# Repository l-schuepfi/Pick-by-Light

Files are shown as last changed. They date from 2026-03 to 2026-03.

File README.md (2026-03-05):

# Entwicklung eines Pick-by-Light-Systems zur Effizienzsteigerung in der Kommissionierung

## Projektbeschreibung

Im Rahmen dieser Projektarbeit wurde ein bestehendes Pick-by-Light-System in der Lernfabrik (KA.409) der Technischen Hochschule Nürnberg erneuert und erweitert. Ziel war die Effizienzsteigerung im Kommissionierprozess durch eine automatisierte Auftragsselektion, Eingriffsüberwachung und Stückzahlüberprüfung. Das System wurde auf Basis eines Raspberry Pi 4B und eines Arduino Uno realisiert und ist vollständig in Python (Raspberry Pi) bzw. C++ (Arduino) implementiert.

| VORHER | NACHHER |
| :---: | :---: |
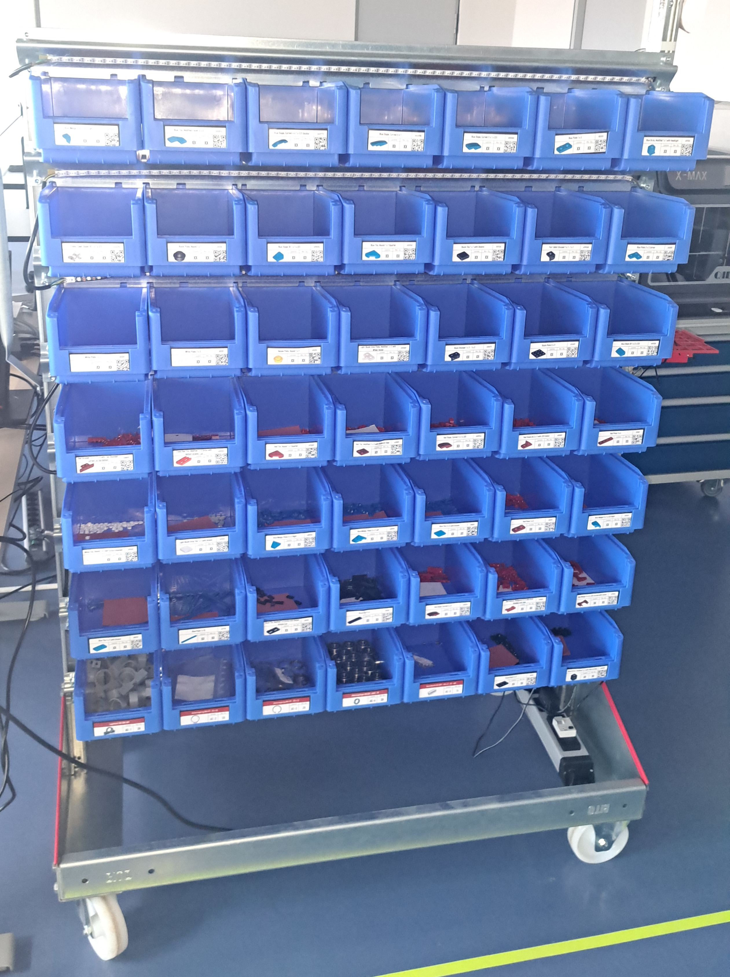
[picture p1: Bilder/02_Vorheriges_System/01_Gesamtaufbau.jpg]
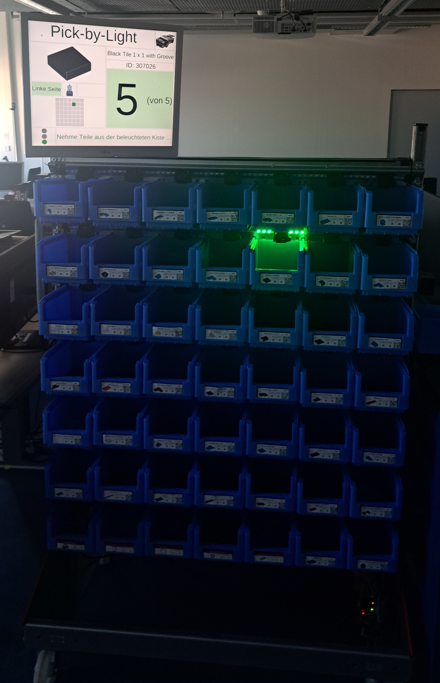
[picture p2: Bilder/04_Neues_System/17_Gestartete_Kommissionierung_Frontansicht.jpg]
|  |  |

**Kernkomponenten:**

- **RFID-basierte Auftragsselektion** – Automatische Erkennung der eingeführten Kiste
- **Infrarot-Eingriffsüberwachung** – Erkennung von Entnahmen aus den Kisten
- **Wägezelle zur Stückzahlüberprüfung** – Gewichtsbasierte Kontrolle der entnommenen Teile
- **LED-Streifen & Monitor (HMI)** – Visuelle Führung des Kommissionierers

## Konzeptionierung inkl. Bewertung

Die Konzeptionierung orientierte sich am mechatronischen V-Modell. In einem ersten Schritt wurden auf Basis einer Swimlane-Funktionsstruktur die Teilfunktionen des Systems identifiziert.

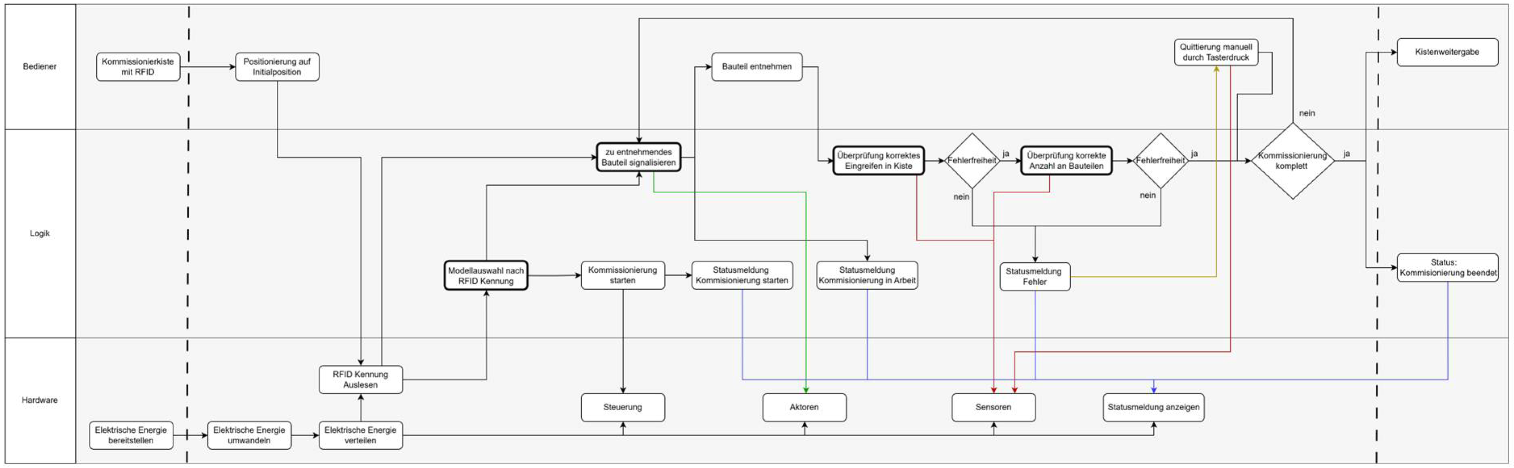
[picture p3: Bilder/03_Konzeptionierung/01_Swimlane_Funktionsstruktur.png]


### Anforderungsliste

Die Anforderungsliste definiert die funktionalen und nicht-funktionalen Anforderungen an das System, z. B. Fehlerraten der Sensorik (< 0,5 %), Kostenziel (300 €), maximales Gesamtgewicht (< 200 kg) und Einarbeitungszeit.

### Morphologischer Kasten

Für jede Teilfunktion wurden im morphologischen Kasten mehrere technische Lösungsvarianten gegenübergestellt – darunter verschiedene Identifikationsverfahren (RFID, Barcode, QR-Code), Sensorprinzipien zur Eingriffsüberwachung (Infrarot, Ultraschall, Laser) und Möglichkeiten zur Stückzahlprüfung (Waage, Kamera, manuell).

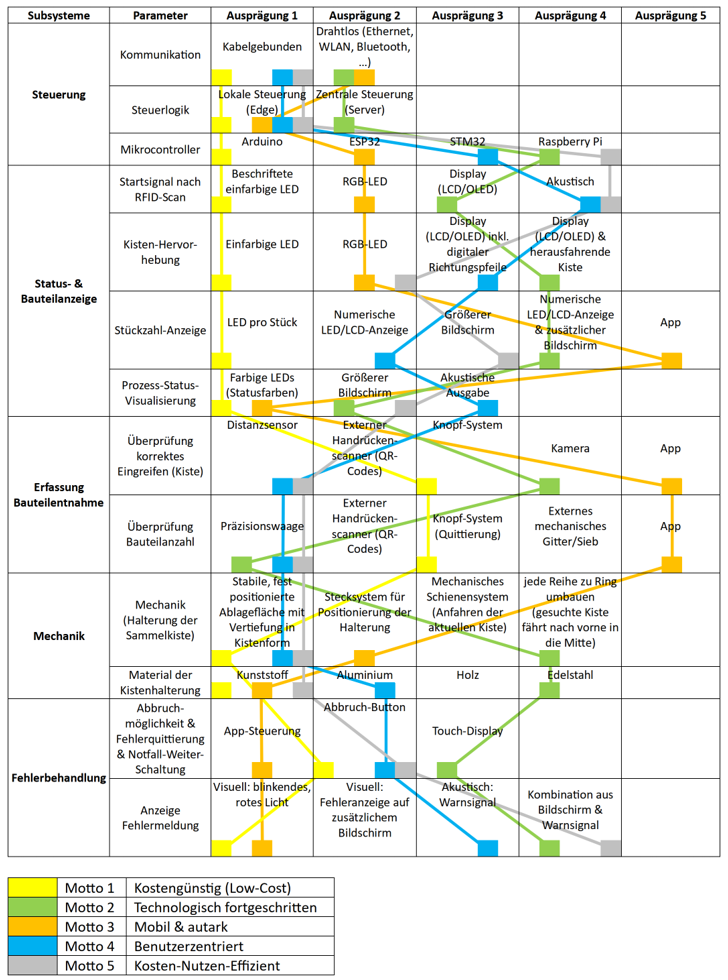
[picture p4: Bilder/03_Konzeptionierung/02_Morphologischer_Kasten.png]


### Paarweiser Vergleich

Über einen konsolidierten paarweisen Vergleich wurde die Gewichtung der einzelnen Anforderungen bestimmt. Drei Personen haben unabhängig voneinander bewertet, um eine möglichst objektive Priorisierung zu erreichen.

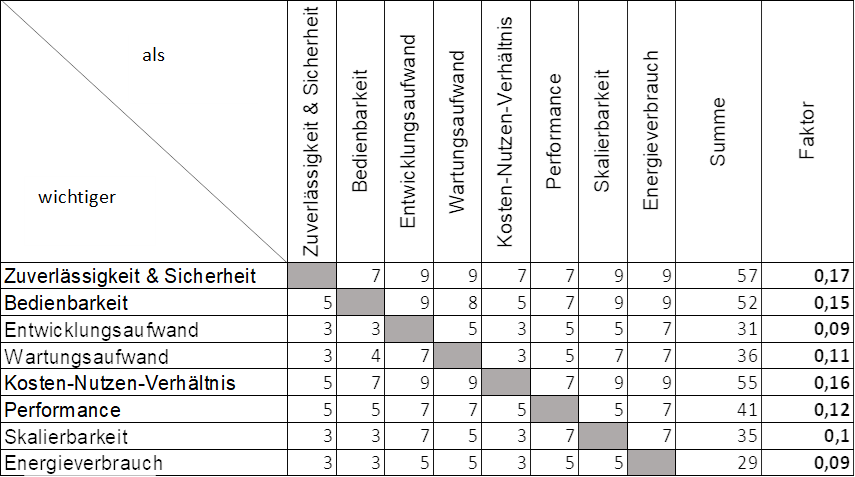
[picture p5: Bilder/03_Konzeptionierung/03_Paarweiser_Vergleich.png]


### Nutzwertanalyse

Auf Basis des paarweisen Vergleichs wurde eine Nutzwertanalyse durchgeführt, um die beste Gesamtlösung aus den Varianten des morphologischen Kastens zu ermitteln. Das gewählte Konzept kombiniert RFID für die Auftragsselektion, Infrarot-Module für die Eingriffsüberwachung und eine Wägezelle für die Stückzahlüberprüfung.

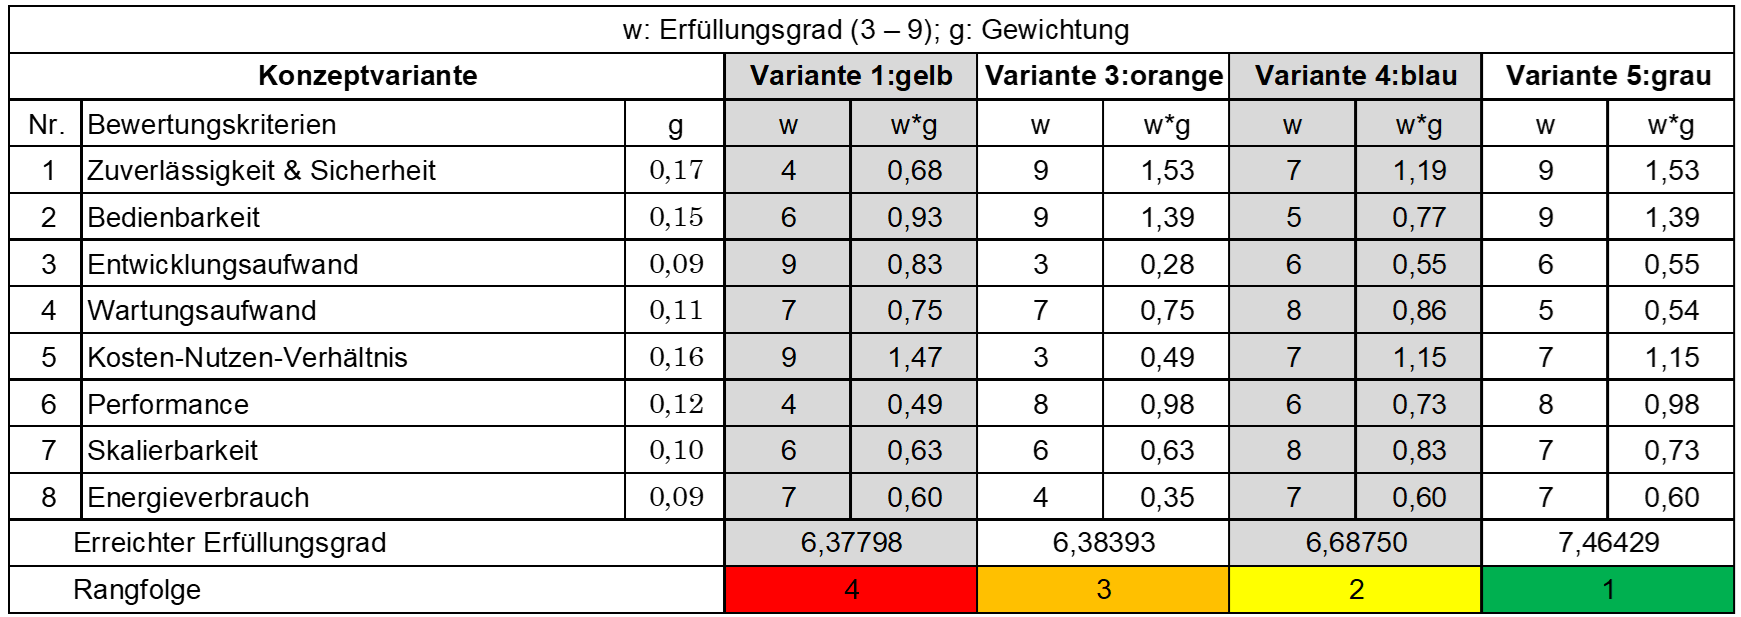
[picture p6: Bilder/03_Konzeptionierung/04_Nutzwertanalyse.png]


## Umsetzung

### Kommissionierungsauswahl – RFID

Jede Kiste besitzt einen RFID-Transponder, der beim Einschieben in die Halterung vom RFID-Modul (RC522) über SPI ausgelesen wird. Anhand der UID wird der zugehörige Kommissionierauftrag aus einer Excel-Datenbank geladen. Das RFID-Lesegerät ist in einem 3D-gedruckten Gehäuse in die Kistenhalterung integriert, um einen zuverlässigen Leseabstand zum Transponder sicherzustellen.

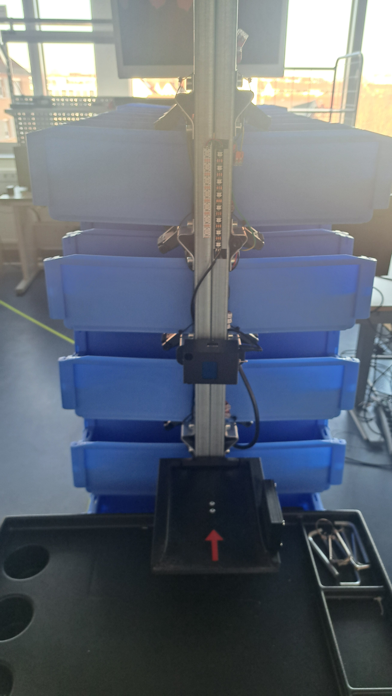
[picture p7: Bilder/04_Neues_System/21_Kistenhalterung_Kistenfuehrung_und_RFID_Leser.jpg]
Kistenfuehrung und RFID-Leser


### Eingriffsüberprüfung – Infrarot

Vor jeder Kiste sitzt ein Infrarot-Modul bestehend aus einer IR-Diode (Sender) und einem IR-Empfänger (TSSP4P38, 38 kHz Trägerfrequenz). Die Dioden werden über eine MOSFET-Schaltung mit einem gepulsten 5 V-Signal angesteuert. Die IR-Empfänger werden über MCP23017-I/O-Expander per I2C am Raspberry Pi ausgelesen. Beim Eingriff in eine Kiste wird der IR-Strahl frühzeitig reflektiert und der Eingriff aufgrund erhöhter Signalstärke erkannt. Die Module sind in 3D-gedruckten Gehäusen mit einstellbarem Sendewinkel verbaut. Beim Systemstart erfolgt eine automatische Kalibrierung jedes Moduls.

### Stückzahlüberprüfung – Waage

Eine 1 kg-Wägezelle mit HX711-ADC wird über den Arduino Uno ausgelesen, da der Raspberry Pi aufgrund seines Betriebssystem-Timings keine stabilen Messwerte liefern konnte. Die Kommunikation zwischen Arduino und Raspberry Pi erfolgt über die serielle USB-Schnittstelle. Das System erkennt Gewichtssprünge und berechnet über das bekannte Einzelgewicht der Bauteile die Anzahl der entnommenen Teile. Die Kalibrierung der Waage kann über einen langen Taster-Druck gestartet werden und nutzt ein 200 g-Referenzgewicht. Der Kalibrierungswert wird im EEPROM des Arduino gespeichert.

Die Wägezelle ist als zentrales Verbindungselement zwischen Trägergestell und Kistenaufnahme montiert, wobei die einseitige Befestigung die elastische Verformung für das Messprinzip gewährleistet.

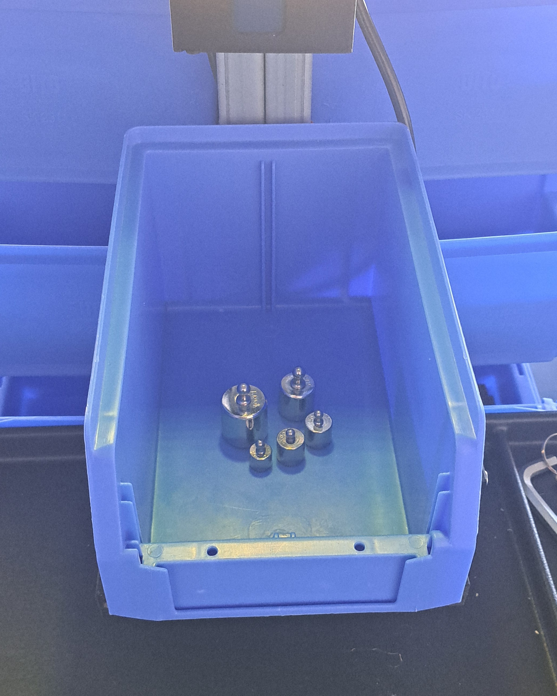
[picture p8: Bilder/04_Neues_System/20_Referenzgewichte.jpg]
Referenzgewichte an Waage


### Signalisierung zu entnehmende Kiste und Anzahl der zu entnehmenden Teile

#### LED-Strip

Zwei WS2812B-LED-Streifen signalisieren dem Kommissionierer die aktuell zu entnehmende Kiste (grün leuchtend). Die Ansteuerung erfolgt über den Raspberry Pi, wobei ein SN74AHCT125N Level-Shifter die 3,3 V-Signale auf die benötigten 5 V anhebt.

#### HMI

Die grafische Oberfläche läuft als Tkinter-Anwendung auf dem Raspberry Pi und zeigt auf einem Monitor den aktuellen Kommissionierstatus, die zu entnehmende Stückzahl und Fehlermeldungen an. Da die GUI-Mainloop und die Sensorauswertung parallel laufen müssen, wurde die Architektur auf drei Prozesse (Multiprocessing) aufgeteilt:

1. **GUI-Prozess** – Aktualisierung der Anzeige
2. **Messschleife** – Auslesung der IR-Module über I2C
3. **Wägezellen-Prozess** – Auslesen der Gewichtswerte über den Arduino

Die Kommunikation zwischen den Prozessen erfolgt über Queues.

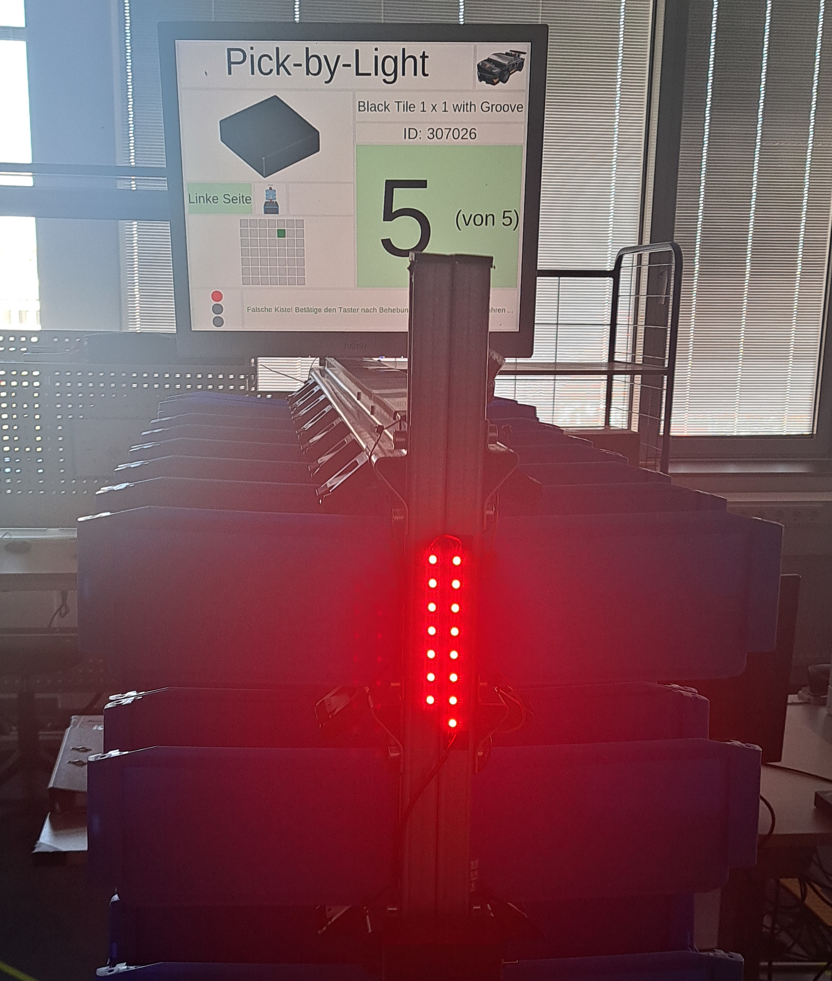
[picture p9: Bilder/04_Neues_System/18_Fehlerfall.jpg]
Fehlerfall


### Systemintegration und Realisierung

- **Controller:** Raspberry Pi 4B (Hauptcontroller) + Arduino Uno (Waage + IR-Pulssteuerung)
- **Hutschiene:** Alle Elektronikbauteile sind modular über DIN-Schiene montiert
- **Schaltnetzteil:** 50 W / 10 A Netzteil für die IR-Dioden, in einem Schutzgehäuse verbaut
- **MOSFET-Schaltung:** IRLZ44N (N-Kanal) + IXTP96P085T (P-Kanal) zur Erzeugung des 38 kHz-Pulssignals auf einer Lochrasterplatine
- **Taster:** Interrupt-basierte Auswertung am GPIO26 mit Unterscheidung zwischen kurzem Druck (Weiterschalten), langem Druck (Kalibrierung / Zurückschalten) und Doppeldruck (Abbruch)
- **Kistenhalterung:** 3D-gedruckte Führung mit Nut-Feder-Prinzip für reproduzierbare Positionierung der Kiste und integriertem Kabelkanal
- **Autostart:** Das Programm startet automatisch nach dem Hochfahren des Raspberry Pi

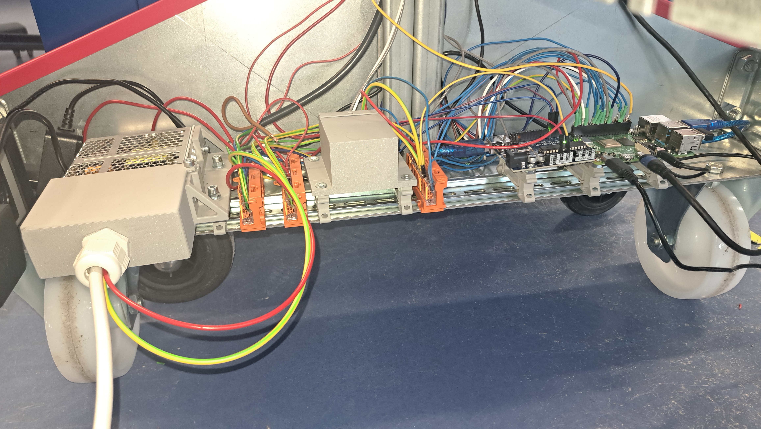
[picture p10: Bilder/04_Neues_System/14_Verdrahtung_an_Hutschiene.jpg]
Verdrahtung an Hutschiene


## Validierung und Tests

Die Validierung erfolgte anhand der definierten Anforderungsliste. Die meisten funktionalen Anforderungen konnten bestätigt werden, einige Punkte waren zum Testzeitpunkt nicht prüfbar (z. B. Gesamtgewicht, Energieverbrauch, Einarbeitungszeit).

| Teilsystem | Fehlerrate (gemessen) | Fehlerrate (Soll) | Ergebnis |
|---|---|---|---|
| **RFID-Erkennung** | 0 % (30 Versuche) | < 0,5 % | ✅ Erfüllt |
| **Eingriffsüberwachung** | 12,5 % (14 Kisten × 20 Zyklen) | < 0,5 % | ❌ Nicht erfüllt |
| **Stückzahlüberprüfung** | 22,5 % (4 Teile × 3 Mengen × 10 Zyklen) | < 0,5 % | ❌ Nicht erfüllt |

Die Eingriffsüberwachung ist stark abhängig von der Geschwindigkeit des Bedieners – langsame Eingriffe werden zuverlässig erkannt, schnelle nicht immer. Das Kostenziel von 300 € wurde mit ca. 500 € überschritten, hauptsächlich durch Leitungen und Verbindungselemente.

## Verbesserungsmöglichkeiten

- **Infrarot-Sensorik:** Kürzere Sende-/Pausenzeiten (< 120 ms / < 380 ms) und angepasster Duty Cycle könnten schnelle Eingriffe besser erkennen. Alternative Kalibrierungsverfahren (Median statt Mittelwert) wären ebenfalls vielversprechend.
- **LED-Streifen:** Austausch des fragilen Systems empfohlen; einheitliche Farbcodierung und Stützkondensator am Level-Shifter nachrüsten.
- **Waage:** Bedingung einbauen, dass vor Waagenauswertung ein korrekter IR-Eingriff erkannt sein muss. Negative Sprünge als Fehlermeldung auswerten.
- **RFID:** Beschreibung der Tags mit Daten statt UID-Zuordnung im Code, um neue Kisten ohne Programmänderung einbinden zu können.
- **Verkabelung:** Farbcodierung vereinheitlichen (aktuell teils grün-gelb als GND statt normgerecht als PE). Alternative Kommunikationswege (z. B. Bluetooth) zur Reduzierung der Leitungsintensität prüfen.
- **Software:** Tonausgabe bei Fehlern über USB-Soundkarte, schönere GUI, LED-Zuordnung austauschfreundlicher gestalten.

## Fazit und Ausblick

Das Pick-by-Light-System wurde erfolgreich als funktionsfähiger Prototyp umgesetzt. Die Auftragsselektion per RFID funktioniert zuverlässig (0 % Fehlerrate). Die Eingriffsüberwachung und Stückzahlüberprüfung zeigen grundsätzliche Funktionsfähigkeit, erreichen die geforderten Fehlerraten aber noch nicht. Insbesondere die Abhängigkeit der IR-Erkennung von der Eingriffgeschwindigkeit und die Drift der Wägezellenwerte stellen Herausforderungen dar, die durch die vorgeschlagenen Optimierungen adressiert werden können.

Das System bietet eine solide Grundlage für zukünftige Weiterentwicklungen im Rahmen der Lernfabrik.

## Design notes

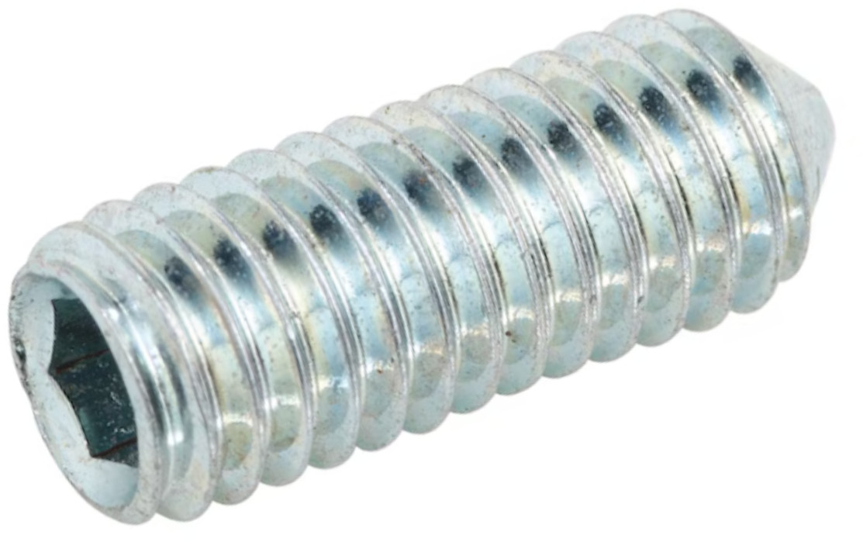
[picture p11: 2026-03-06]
Code/Raspberry_Pi/img/Left_Side/L007005.jpg

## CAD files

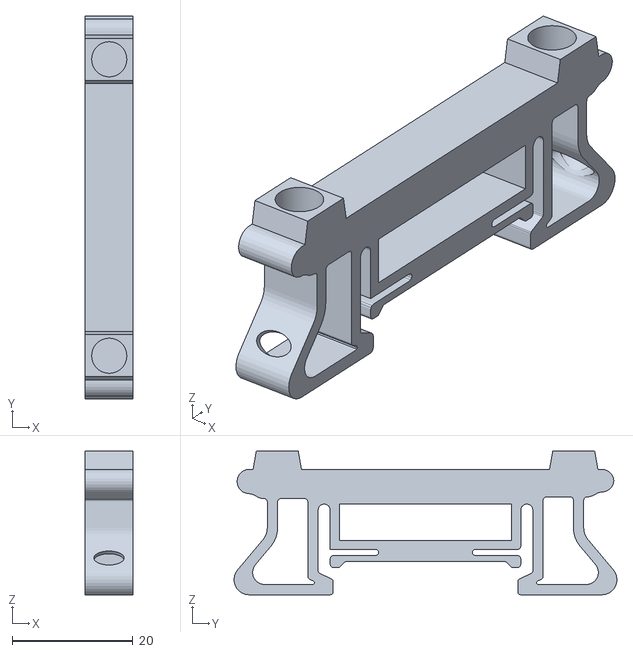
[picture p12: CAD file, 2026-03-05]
CAD/Hutschiene/clips_2.stl
8.00 x 63.3 x 23.7

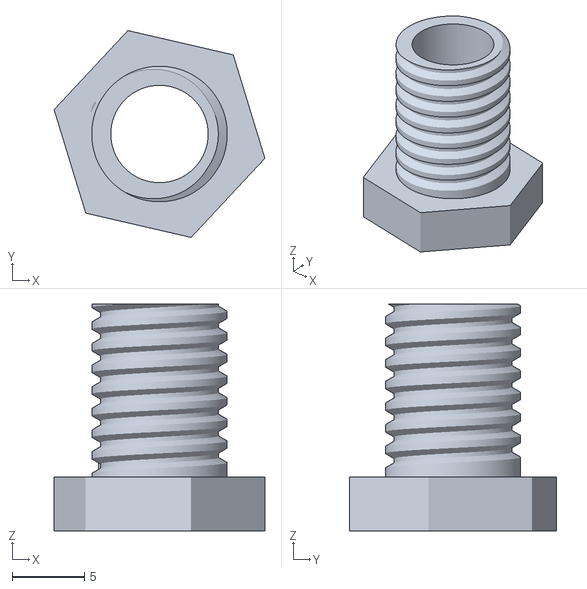
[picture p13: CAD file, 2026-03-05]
CAD/IRModul/Schraube_M10x1.stl
14.6 x 14.4 x 15.8

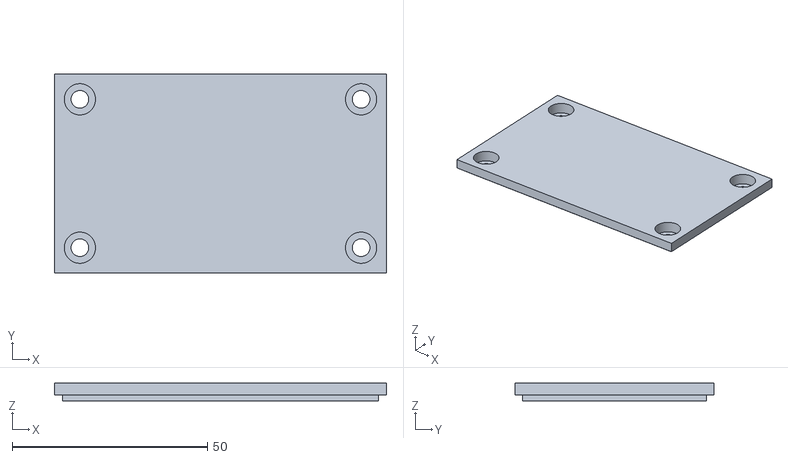
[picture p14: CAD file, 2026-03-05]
CAD/Kistenhalterung/RFID_Deckel.stl
85.0 x 51.0 x 4.50

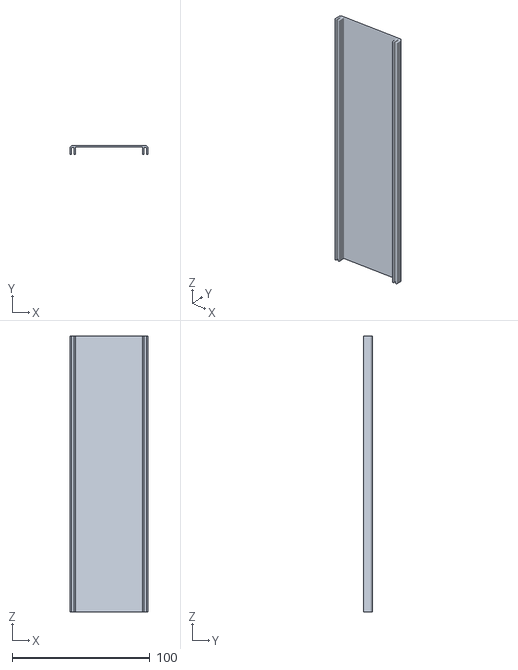
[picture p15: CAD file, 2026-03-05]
CAD/Sonstiges/Kabelkanaldeckel_2.stl
56.6 x 6.50 x 200.0

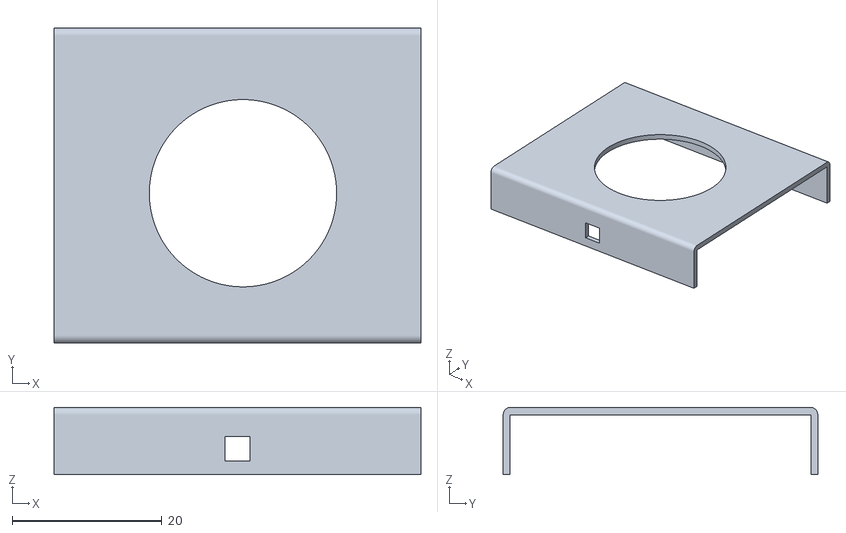
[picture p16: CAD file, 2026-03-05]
CAD/Hutschiene/Deckel_Platinegehäuse.stl
49.0 x 42.0 x 9.00

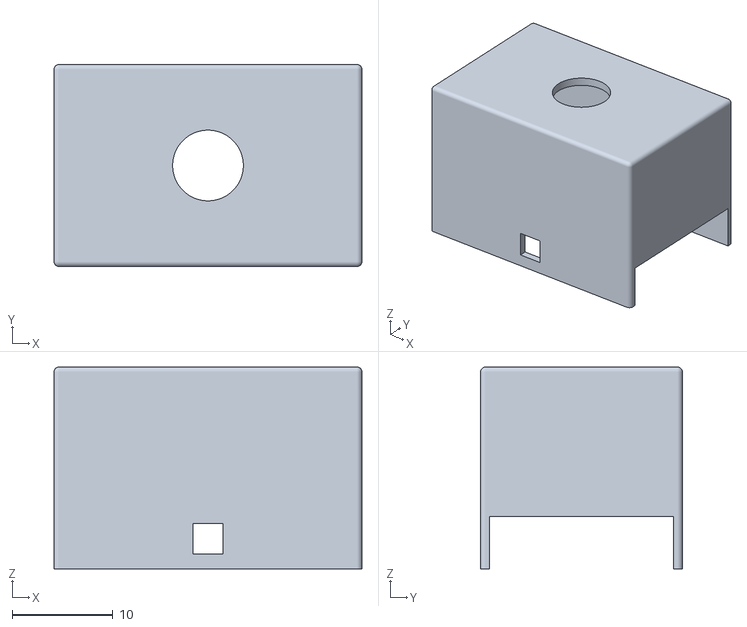
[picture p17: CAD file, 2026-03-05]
CAD/IRModul/Deckel_lang.stl
30.5 x 20.0 x 20.0

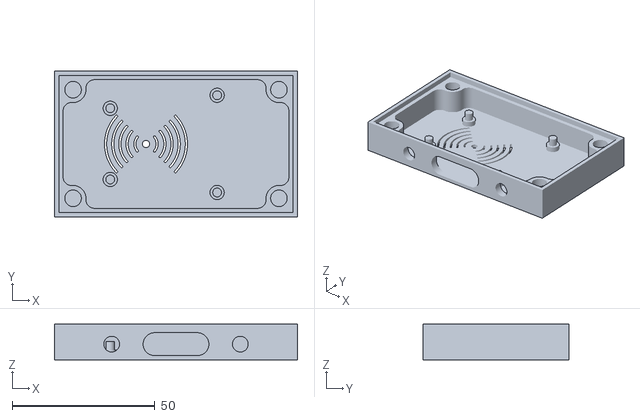
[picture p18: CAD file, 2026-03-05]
CAD/Kistenhalterung/RFID_Gehäuse.stl
85.0 x 51.0 x 12.5

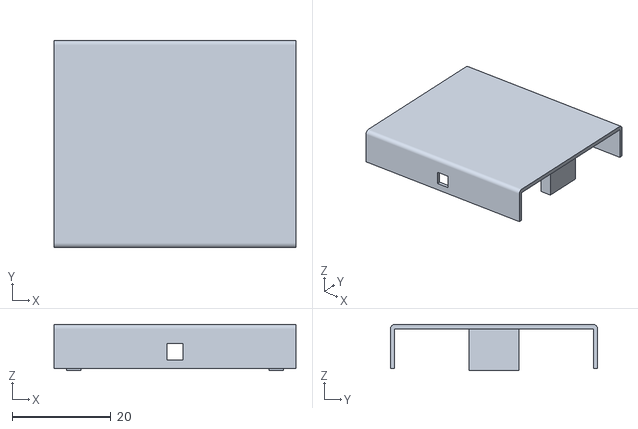
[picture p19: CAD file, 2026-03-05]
CAD/Sonstiges/MCP_Deckel.stl
49.0 x 42.0 x 9.40

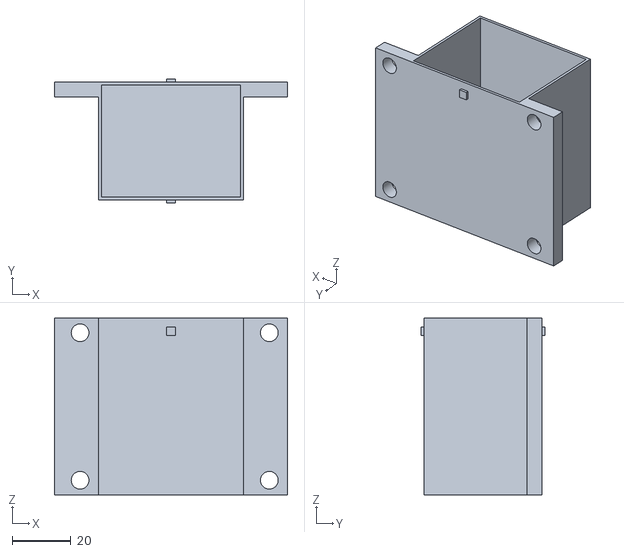
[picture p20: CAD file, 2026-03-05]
CAD/Hutschiene/Platine_Halterung.stl
79.0 x 42.0 x 60.0

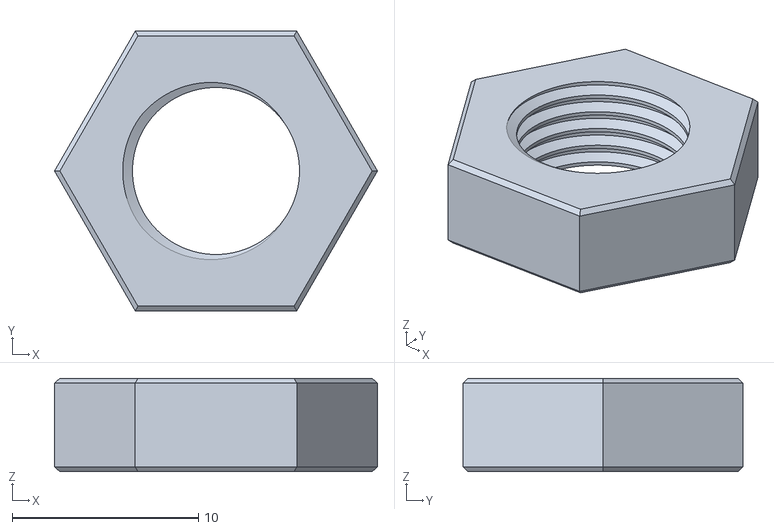
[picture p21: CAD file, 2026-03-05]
CAD/IRModul/Mutter M10x1_flach.stl
17.3 x 15.0 x 5.00

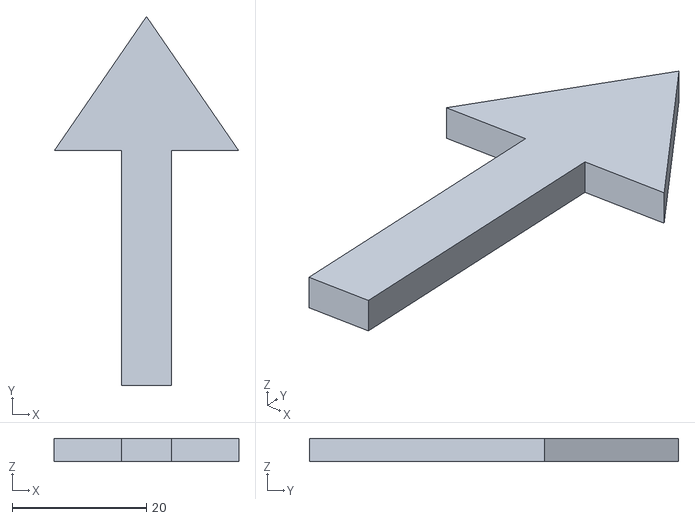
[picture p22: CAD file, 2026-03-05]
CAD/Kistenhalterung/Pfeil.stl
27.5 x 55.0 x 3.50

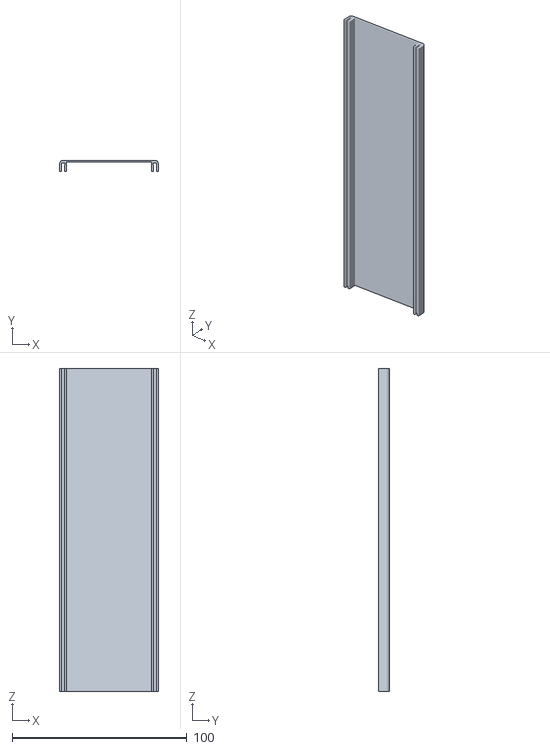
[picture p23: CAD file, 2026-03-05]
CAD/Sonstiges/Kabelkanaldeckel_18.5cm.stl
56.6 x 6.50 x 185.0

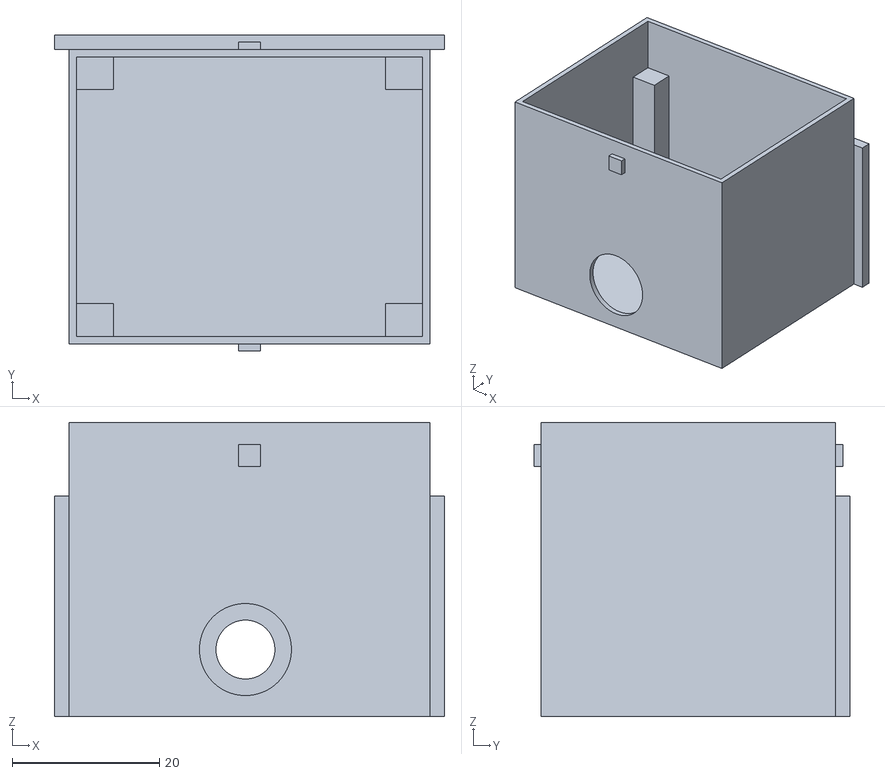
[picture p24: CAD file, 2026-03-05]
CAD/Sonstiges/MCP_Gehäuse.stl
53.0 x 43.0 x 40.0

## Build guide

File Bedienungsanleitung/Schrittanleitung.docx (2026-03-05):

Bedienungsanleitung Pick-by-Light-System der Lernfabrik

In diesem Dokument soll beschreiben werden, wie das Pick-by-Light-System der Lernfabrik (KA.409) zu bedienen ist.

Grundsätzlich kann damit die Kommissionierung der folgenden drei Legoautos begleitet werden:

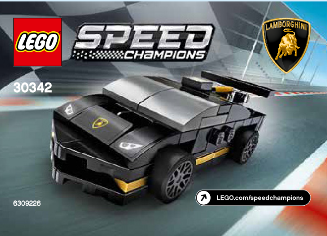
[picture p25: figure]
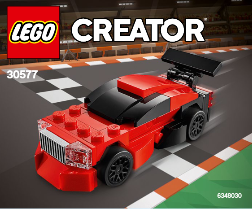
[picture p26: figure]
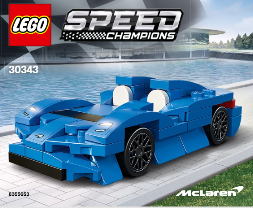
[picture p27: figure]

Bedienreihenfolge:

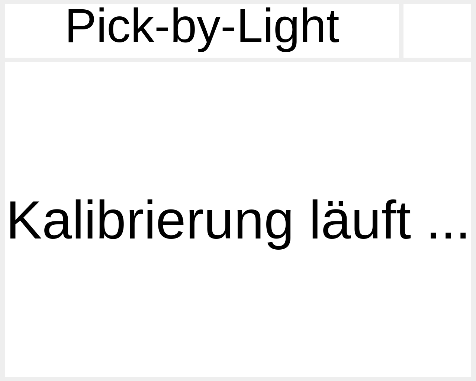
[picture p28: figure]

Schritt 1: Versorgung aktivieren (Steckdose einstecken, Schalter unten umlegen)

Hier ist abzuwarten, bis das System hochgefahren ist.

Schritt 2: Kalibrierung

Hier ist einfach abzuwarten (grob 5-10 Sekunden)

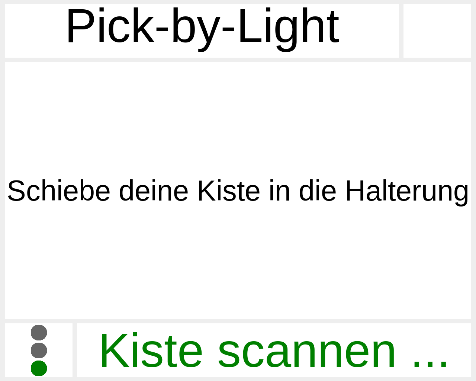
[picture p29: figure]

Schritt 3: Auftragsselektion

Im Durchlaufregal des Labors sind blaue Kisten, die seitlich mit einem RFID-Tag beklebt sind. Diese Kisten sind so einsortiert und der jeweilige Kanalplatz auch beschriftet, dass jeder Kanalplatz für einen Typen Legoauto steht. Allerdings sind zum Zeitpunkt der Abgabe nur drei Kisten funktionstüchtig (andere werden vom RFID-Scanner nicht erkannt)

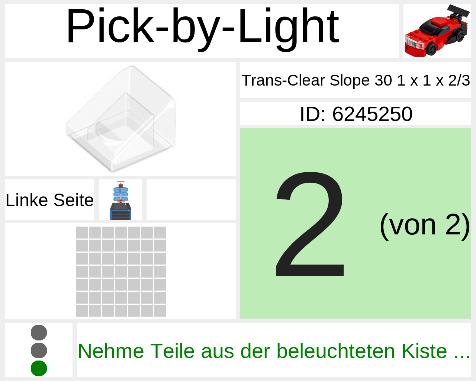
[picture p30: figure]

Schritt 4: in Startposition bringen

Nachdem eine Kiste mit gewolltem Legoautotypen entnommen wurde, muss diese nun in die Startposition am Pick-by-Light-System eingesetzt werden. Hierbei wird automatisch der RFID-Tag der Kiste erkannt und ausgelesen und die Kommissionierung startet. Der Bildschirmscreen ändert sich.

Bemerkung: Die Kiste in Startposition soll erst nach Ende der Kommissionierung wieder aus dieser Position entfernt werden.

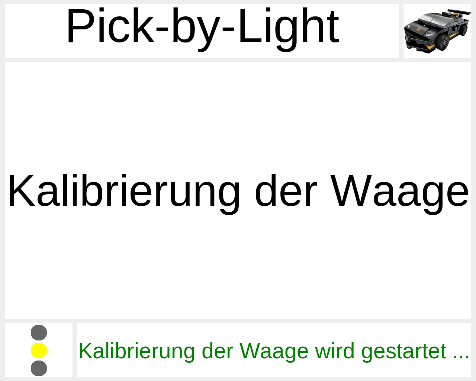
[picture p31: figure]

Optionaler Schritt 5: Kalibrierung

5.1 Durch einen langen Druck auf den Taster wird der Kalibierungsmodus der Wägezelle aktiviert (nur möglich solange noch kein Kisteneingriff erkannt wurde)

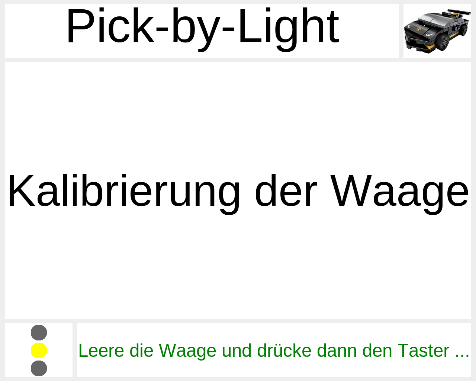
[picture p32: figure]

5.2 Hierfür muss die Kiste leer sein → ggf. leeren

5.3 Bestätigung per Taster

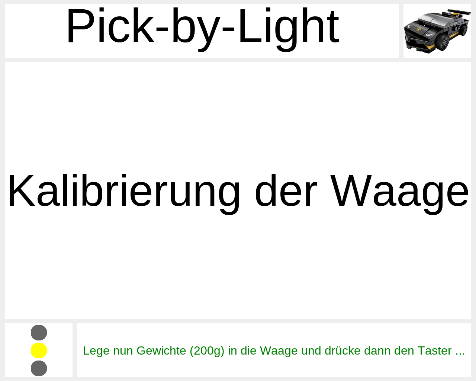
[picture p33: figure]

5.4 200gr Referenzgewicht in die Kiste legen

5.5. Bestätigung per Taster

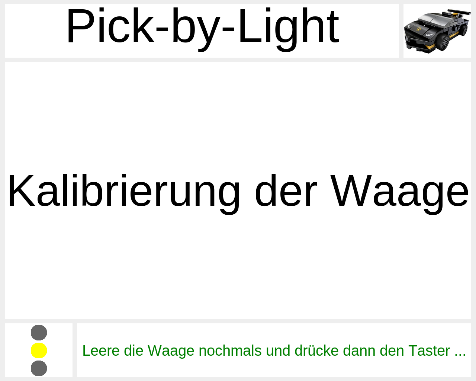
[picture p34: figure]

5.6 Referenzgewicht entnehmen

5.7 Bestätigung per Taster

Anschließend startet die Kommissionierung und der Screen ändert sich.
Der Kommissionierer wird auch vom Bildschirm durch entsprechende Anweisungen unterstützt.

Schritt 5: Kommissionierung

Nun werden am Bildschirm die Position sowie Anzahl des zu entnehmenden Teiles angezeigt. Zusätzlich leuchten die LEDs des LED-Strips oberhalb der zu entnehmenden Kiste.

Schritt 5.1: Entnahme

Entnehmen Sie die angezeigte Anzahl aus der visuell hervorgehobenen Kiste.

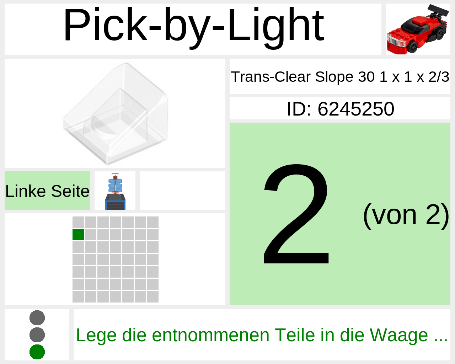
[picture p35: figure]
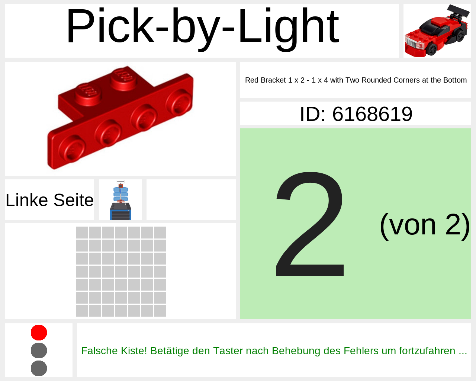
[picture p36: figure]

Ein Eingreifen in eine andere Kiste wird ebenfalls erkannt und führt zur Fehlerauslösung.

- Eine Fehlerquittierung durch einen Druck auf den Taster ist nun notwendig. Zuvor sollte jedoch der Fehler kontrolliert und ggf. behoben werden.

Schritt 5.2: Stückzahlüberprüfung

Legen Sie die entnommenen Teile in die Kommissionierkiste. Bei korrekter Anzahl wird der nächste Screen mit dem neuen zu entnehmenden Bauteil angezeigt.

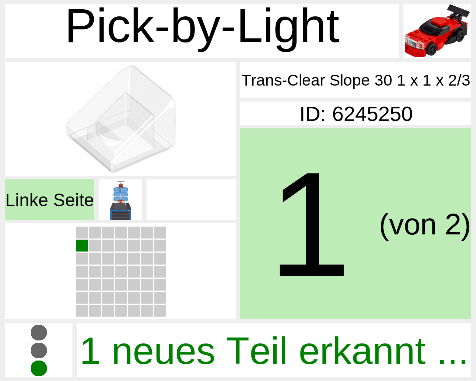
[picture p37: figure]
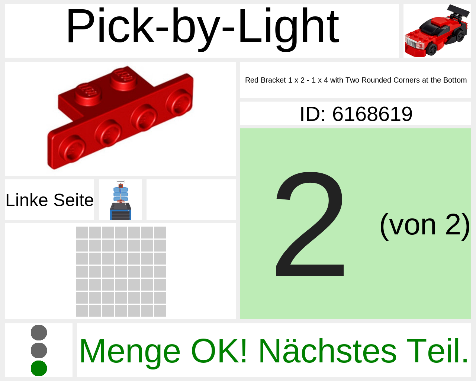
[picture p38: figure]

Eine erhöhte Stückzahl führt zur Fehlerauslösung.

- Eine Fehlerquittierung durch einen Druck auf den Taster ist nun notwendig. Zuvor sollte jedoch der Fehler kontrolliert und ggf. behoben werden.

Schritt 5.3: Wiederholung des Kommisionierschrittes, bis alle benötigten Bauteile gesammelt sind.

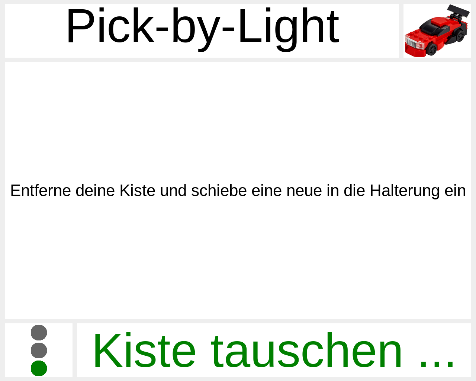
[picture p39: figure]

Schritt 6: Entnahme der Kommissionierkiste.
Durch Einführen einer neuen Kiste wird ein neuer Kommissioniervorgang gestartet.

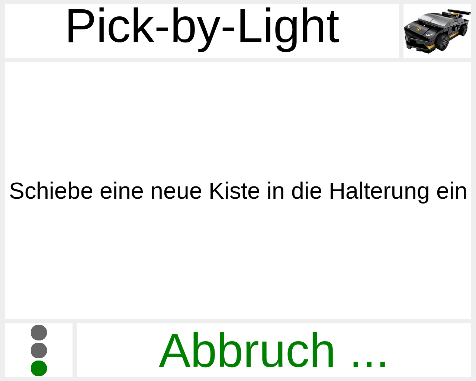
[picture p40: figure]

Abbruchfunktion:

Jederzeit kann über Doppelklick auf den Button die Kommissionierung abgebrochen werden. Danach muss die aktuelle Kiste aus der Schiene entfernt werden und eine neue Kiste eingeführt werden.

Manuelle Schaltung:

Während der Kommissionierung kann über einen kurzen Button-Druck zum nächsten Teil geschaltet werden. Dies sollte angewendet werden, wenn die Waage zu wenige Teile erkannt hat oder zu viele Teile erkannt hat, was zum Fehlerfall oder einer ausbleibenden Weiterschaltung geführt hat. Alternativ kann über einen langen Button-Druck (> 2s) zum vorherigen Teil geschaltet werden. Dies sollte angewendet werden, wenn die Waage zu viele Teile erkannt hat und verfrüht zum nächsten Teil gewechselt hat.

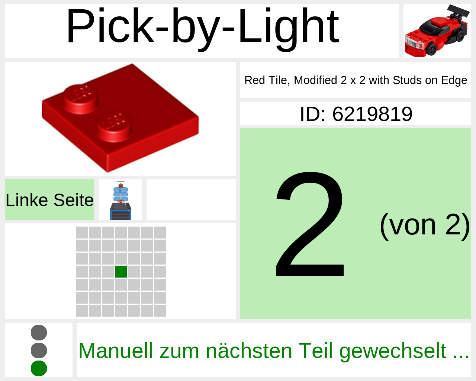
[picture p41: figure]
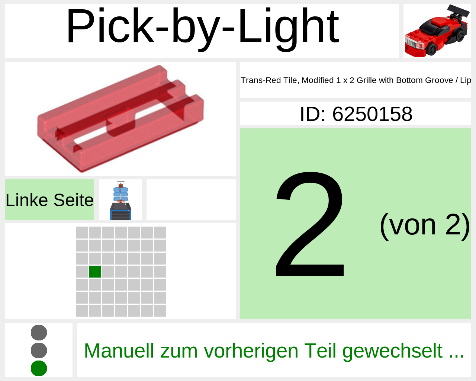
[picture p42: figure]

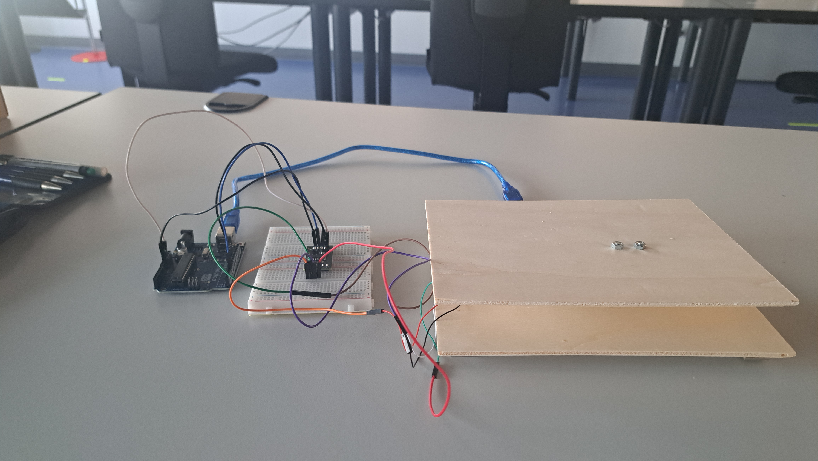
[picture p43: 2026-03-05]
Bilder/04_Neues_System/04_Simpler_Testaufbau_Waage.jpg

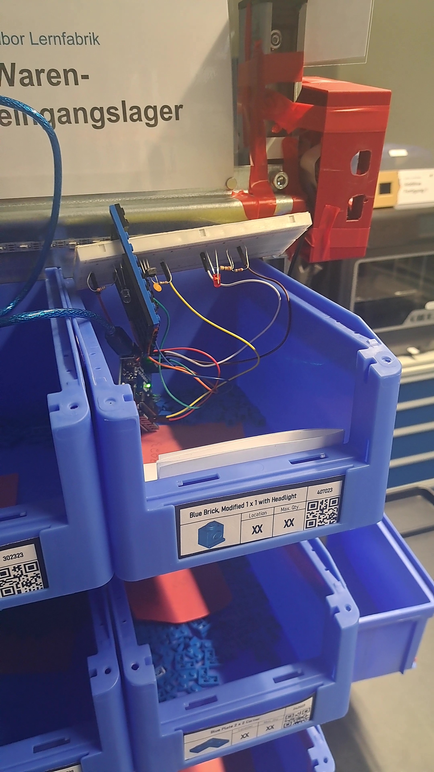
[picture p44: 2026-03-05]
Bilder/04_Neues_System/03_Testaufbau_Eingriffserkennung_an_System.jpg

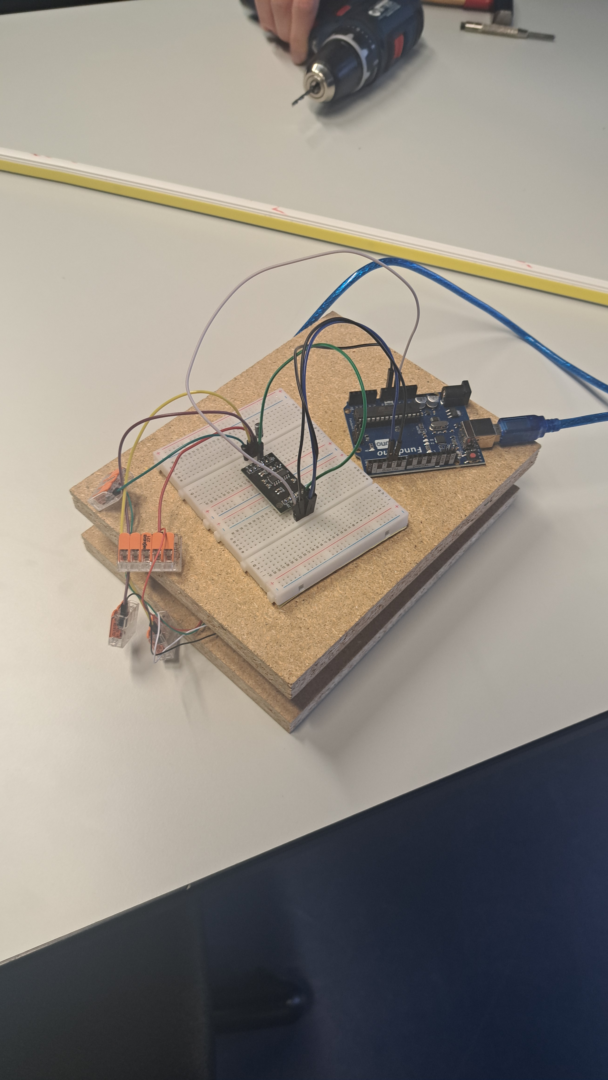
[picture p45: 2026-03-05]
Bilder/04_Neues_System/05_Optimierter_Testaufbau_Waage.jpg

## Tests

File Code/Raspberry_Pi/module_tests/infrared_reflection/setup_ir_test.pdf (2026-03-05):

IR7373C

R1
33

R2

100

TSSP 4P38
V_S
OUT
GND

C1

0.1µ

## Raspberry Pi 4 B

3.5mm

3V3 | 5V
I2C SDA GPIO2 | 5V
I2C SCL GPIO3 | GND
GPIO4 | GPIO14 UART TX
GND | GPIO15 UART RX
GPIO17 | GPIO18 PCM CLK
GPIO27 | GND
GPIO22 | GPIO23
3V3 | GPIO24
SPI MOSI GPIO10 | GND
SPI MISO GPIO9 | GPIO25
SPI SCLK GPIO11 | GPIO8 SPI CE0
GND | GPIO7 SPI CE1
I2C ID GPIO0 | GPIO1 I2C ID
GPIO5 | GND
GPIO6 | GPIO12 PWM0
PWM1 GPIO13 | GND
PWM1 PCM GPIO19 | GPIO16
GPIO26 | GPIO20 PCM DIN
GND | GPIO21 PCM DOUT
USB-C | HDMI-D HDMI-D

Ethernet USB3.0 USB3.0 USB2.0 USB2.0

Klinkenbuchse

Netzstecker

(Raspberry Pi)

USB-C
SCHUKO-Stecker

Fujitsu Monitor

3.5mm

Kalt
Klinkenbuchse
DVI-D
D-Sub VGA

gerätebuchse

Netzstecker - Monitor
Kaltgerätestecker
SCHUKO-Stecker

Steckdosenleiste

Steckdose
Steckdose
Steckdose

Steckdose

Lila

Grün

Schwarz

Gelb-Grün

Gelb-Grün

--- C:\Users\andka\OneDrive\Dokumente\2_Master\2.Semester\3_Projekt\Schaltung\Modultest_IR_ohne_MCP.asc ---

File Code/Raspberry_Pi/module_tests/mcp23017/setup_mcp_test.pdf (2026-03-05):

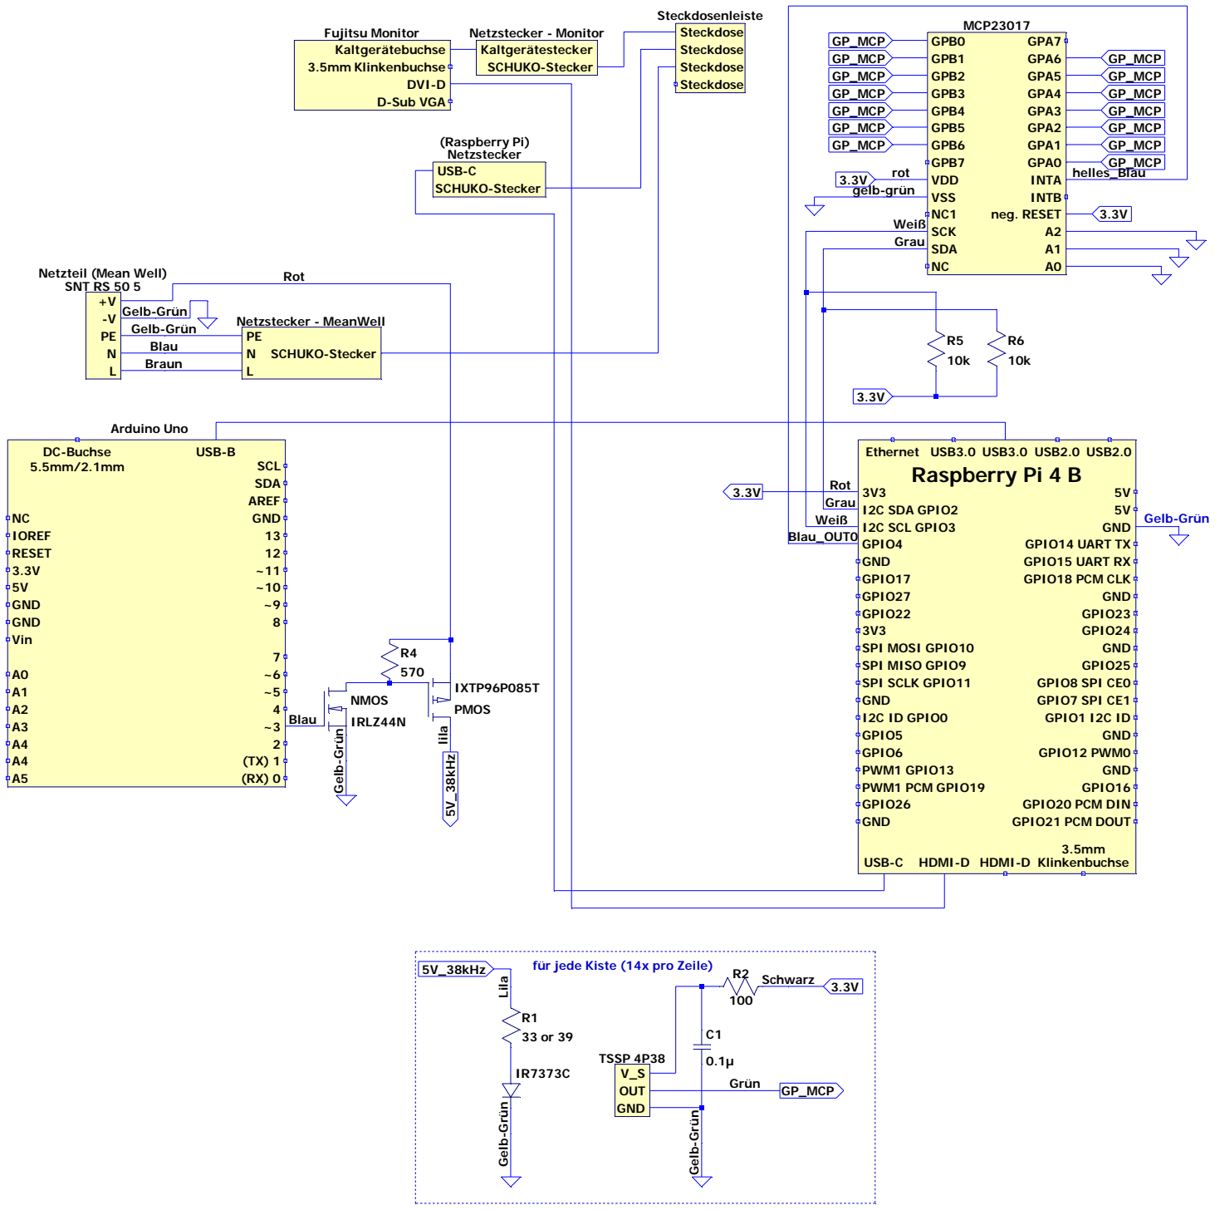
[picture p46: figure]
MCP23017 GPB0 GPB1 GPB2 GPB3 GPB4 GPB5 GPB6 GPB7 VDD VSS NC1 SCK SDA; neg. RESET; INTB; INTA; GPA0; GPA1; GPA2; GPA3; GPA4; GPA5; GPA6; GPA7; TSSP 4P38 V_S OUT GND; Raspberry Pi 4 B; I2C SDA GPIO2; I2C SCL GPIO3; GND; GPIO4; GPIO14 UART TX; GPIO15 UART RX; GPIO17; GPIO18 PCM CLK; GPIO27; GPIO22; GPIO23; GPIO24; SPI MOSI GPIO10; SPI MISO GPIO9; GPIO25; SPI SCLK GPIO11; GPIO8 SPI CE0; GPIO7 SPI CE1; I2C ID GPIO0; GPIO1 I2C ID; GPIO5; GPIO6; GPIO12 PWM0; PWM1 GPIO13; PWM1 PCM GPIO19; GPIO16; GPIO26; GPIO20 PCM DIN; GPIO21 PCM DOUT; USB-C; HDMI-D HDMI-D; Ethernet USB3.0 USB3.0 USB2.0 USB2.0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

--- C:\Users\andka\OneDrive\Dokumente\2_Master\2.Semester\3_Projekt\Schaltung\Modultest_MCP.asc ---

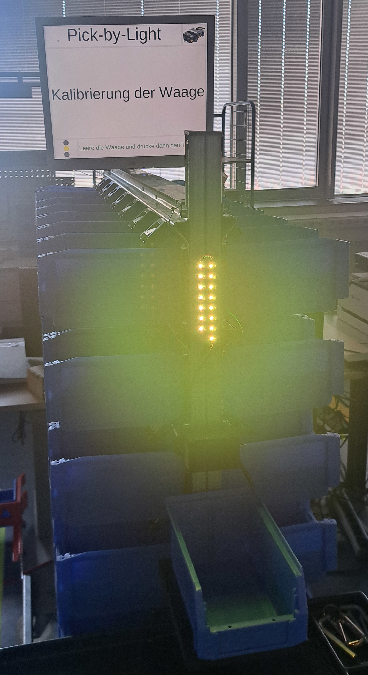
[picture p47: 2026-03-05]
Bilder/04_Neues_System/19_Kalibrierung_der_Waegezelle.jpg

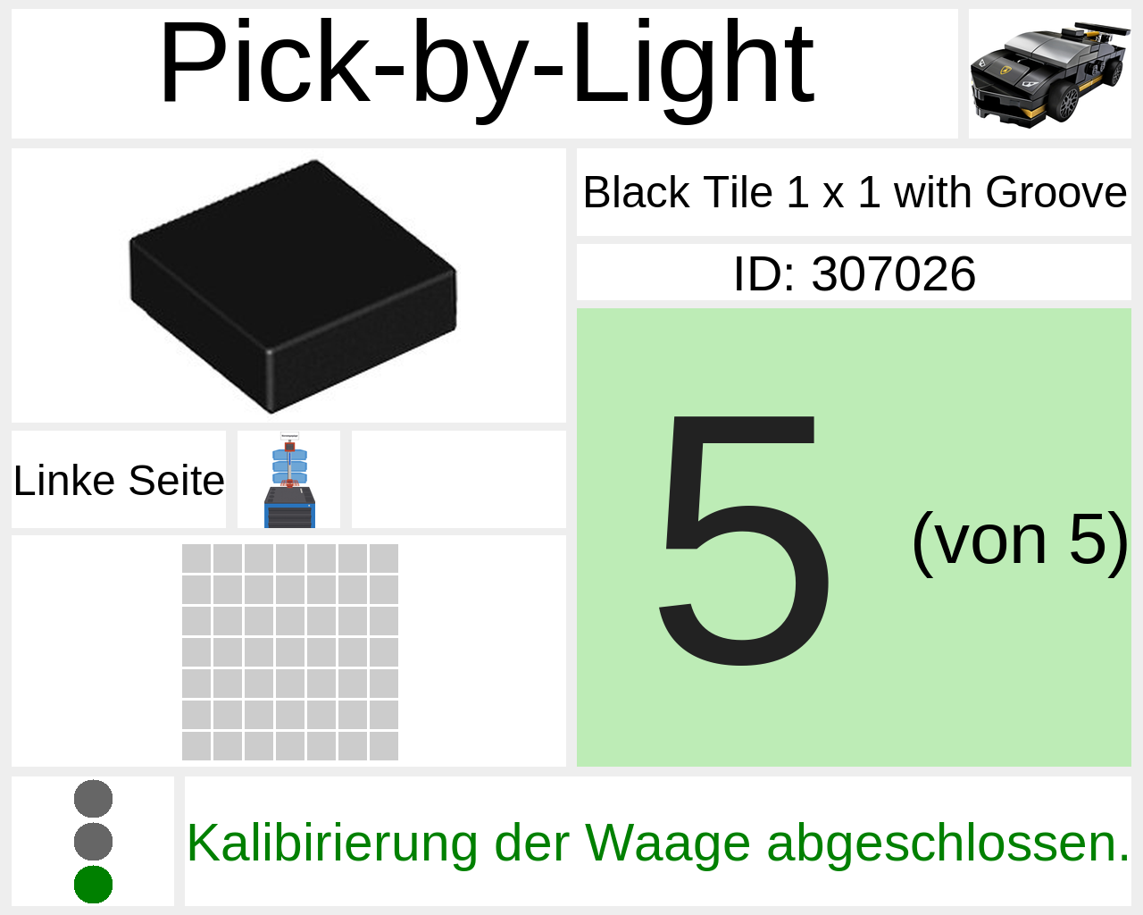
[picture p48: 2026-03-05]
Bilder/05_GUI_Screenshots/17_Fertige_Waagen_Kalibrierung.png

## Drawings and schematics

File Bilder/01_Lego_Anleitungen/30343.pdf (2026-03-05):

123

456

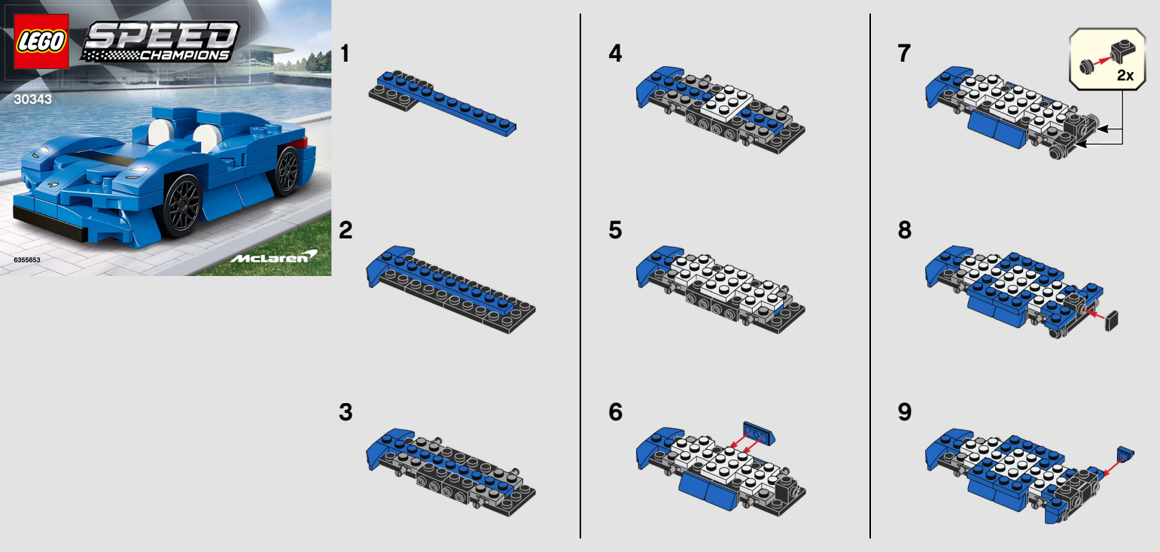
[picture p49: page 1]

13

16

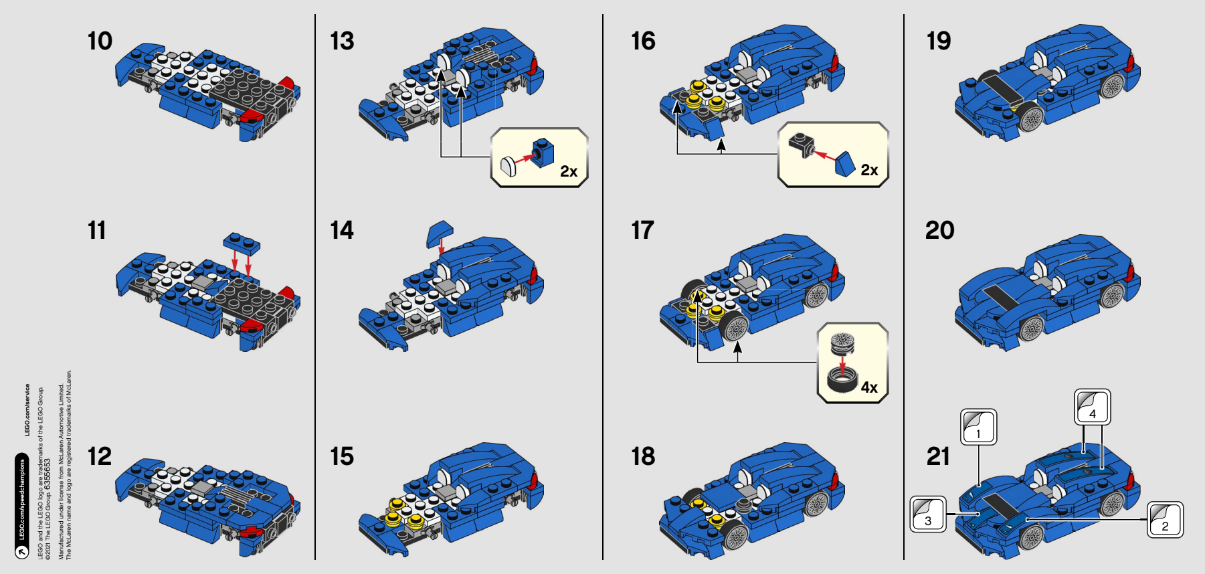
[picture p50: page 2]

The McLaren name and logo are registered trademarks of McLaren.

LEGO.com/service

Manufactured under license from McLaren Automotive Limited.

LEGO and the LEGO logo are trademarks of the LEGO Group.

©2021 The LEGO Group. 6355653

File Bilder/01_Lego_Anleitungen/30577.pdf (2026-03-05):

1234

567

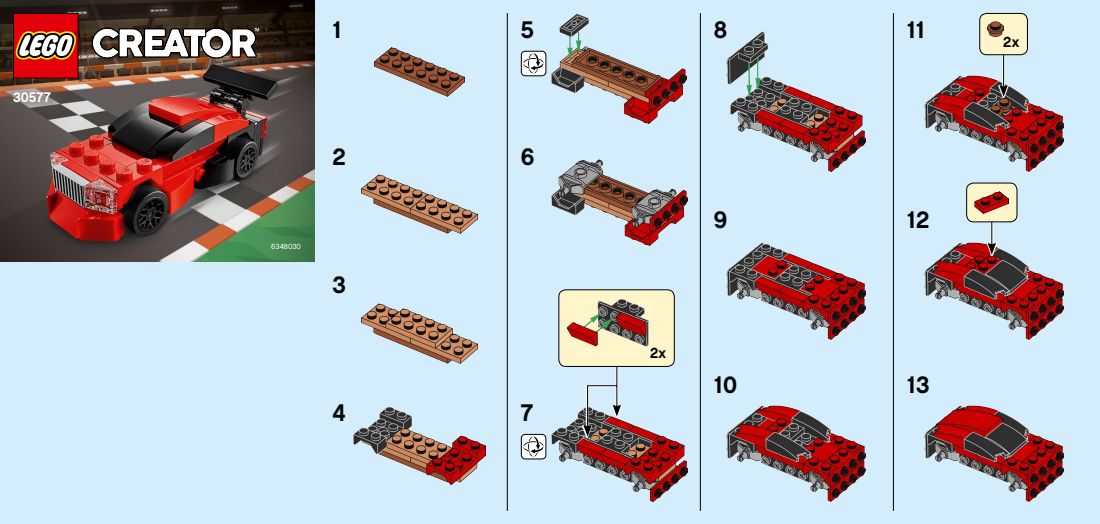
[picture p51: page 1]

1 2
1 2

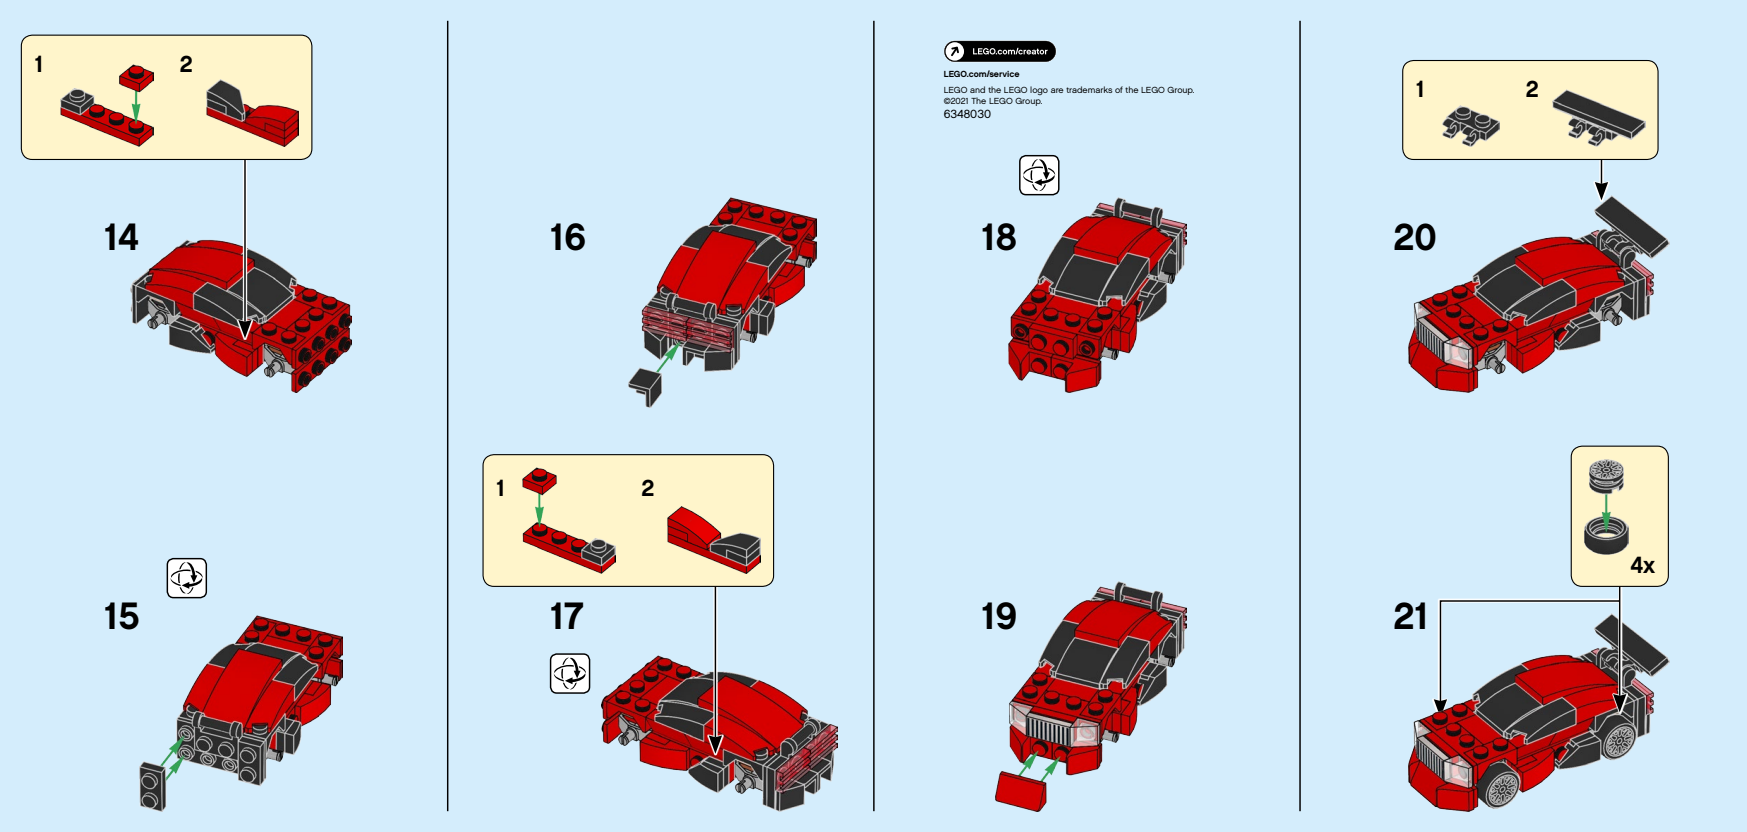
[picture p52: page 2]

LEGO.com/service
LEGO and the LEGO logo are trademarks of the LEGO Group.
©2021 The LEGO Group.

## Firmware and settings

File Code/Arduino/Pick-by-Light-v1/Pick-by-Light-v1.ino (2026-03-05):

/*

   Pick-by-Light System
   -------------------------------------------------------
   Program used to support the Raspberry Pi 4B at the
   Pick-by-Light with controlling the IR-diodes and
   reading correct values from the load cell.

   This program is based on the calibration file from
   Olav Kallhovd's HX711_ADC library.

   It allows calibration of the load cell via the serial
   interface. At startup, the EEPROM value is read from
   the load cell and used as a calibration factor.

   For this purpose, a pulsed signal with a duty cycle
   of approx. 1.5% and 38 kHz is sent to pin 3. It was
   also set to transmit for 120 ms and then pause for
   380 ms.

   Author: Andreas Katzenberger
   Date: 2026-02-22

*/

#include <HX711_ADC.h>
#if defined(ESP8266)|| defined(ESP32) || defined(AVR)
#include <EEPROM.h>
#endif

// Pins
const int irLedPin = 3; // PWM output (OC2B) -> 38kHz signal
const int HX711_dout = 4; // mcu > HX711 dout pin
const int HX711_sck = 5; // mcu > HX711 sck pin

// Global variables for measurement
volatile int burstCycles = 0; // Counts the cycles for the burst timer

// Calculations for timer 2 overflow (clock rate 16 MHz, OCR2A=210 -> cycle time 26.3 µs)
// const int CYCLES_PER_MS = 1000 / 26.316; // ~38 cycles per millisecond
const int BURST_MS = 120; // Transmission time in milliseconds
const int CYCLE_MS = 500; // Total cycle time in milliseconds (120 ms transmission + 380 ms pause)

const int CYCLES_PER_120MS = 38 * BURST_MS; // 4,560 cycles
const int CYCLES_PER_500MS = 38 * CYCLE_MS; // 19,000 cycles

// HX711 constructor:
HX711_ADC LoadCell(HX711_dout, HX711_sck);

const int calVal_eepromAdress = 0;
float calFactor = 1.0;
unsigned long t = 0;

void setup() {
  Serial.begin(57600);
  delay(1);

  // Pin 3 (OC2B) must be output for the 38kHz signal
  pinMode(irLedPin, OUTPUT); 

  // --- TIMER 2 CONFIGURATION ---
  // Disable interrupts to set registers safely
  noInterrupts();

  // 1. TCCR2A (Timer/Counter Control Register A)
  // WGM20 = 1, WGM21 = 0 (Phase Correct PWM, Top is OCR2A)
  // COM2B1 = 1 (Connects pin 3 to the timer: Clear on Compare Match)
  TCCR2A = _BV(WGM20);

  // 2. TCCR2B (Timer/Counter Control Register B)
  // WGM22 = 1 (Phase Correct PWM Mode 5)
  // CS20 = 1 (No prescaler = use 16 MHz clock directly)
  TCCR2B = _BV(WGM22) | _BV(CS20);

  // 3. OCR2A (Output Compare Register A) - Determines the frequency
  OCR2A = 210; // 16 MHz / (2 * 38 kHz) = 210.5

  // 4. OCR2B (Output Compare Register B) - Determines the duty cycle
  // 1.5% Duty Cycle desired:
  OCR2B = 3; // 210 * 0.015 = 3.15

  // Enable Timer 2 overflow interrupt (TOIE2 = 1)
  TIMSK2 = _BV(TOIE2);

  interrupts(); // Interrupts back on

  LoadCell.begin();
  unsigned long stabilizingtime = 2000; // preciscion right after power-up can be improved by adding a few seconds of stabilizing time
  LoadCell.start(stabilizingtime, true);
  if (LoadCell.getTareTimeoutFlag() || LoadCell.getSignalTimeoutFlag()) {
    Serial.println("Timeout, check MCU>HX711 wiring and pin designations");
    while (1);
  }
  else {
    EEPROM.get(calVal_eepromAdress, calFactor);
    LoadCell.setCalFactor(calFactor); // Set calibration value from EEPROM so that calibration is not mandatory when starting the microcontroller
  }
}

// --- INTERRUPT SERVICE ROUTINEN (ISRs) ---

/**
 * ISR for Timer 2 overflow. Controls the 500 ms transmission cycle (120 ms transmission / 380 ms pause).
 */
ISR(TIMER2_OVF_vect) {
  burstCycles++;

  if (burstCycles == CYCLES_PER_120MS) {
    // 1. At the end of the 120 ms burst: Stop transmission (disconnect OC2B from timer 2)
    TCCR2A &= ~_BV(COM2B1); // Disable pin 3 (OC2B)
    
  } else if (burstCycles >= CYCLES_PER_500MS) {
    // 2. At the end of the 500ms cycle: Reset and start transmission
    burstCycles = 0;
    TCCR2A |= _BV(COM2B1); // Connect pin 3 (OC2B) to timer 2 -> Transmission begins
  }
}

void loop() {
  static boolean newDataReady = false;

  // check for new data/start next conversion:
  if (LoadCell.update()) {
    newDataReady = true;
  }

  // get smoothed value from the dataset:
  if (newDataReady) {
    float i = LoadCell.getData();
    Serial.print("Load_cell output val: ");
    Serial.println(i);
    newDataReady = false;
  }

  // receive command from serial terminal
  if (Serial.available() > 0) {
    char inByte = Serial.read();
    if (inByte == 't') {
      LoadCell.tareNoDelay(); //tare
      Serial.println("Tare complete");
    }
    else if (inByte == 'c') {
      LoadCell.setCalFactor(1.0);
      calibrate(); //calibrate
    }
    else if (inByte == 'r') {
      reset();
    }
  }

  // check if last tare operation is complete
  if (LoadCell.getTareStatus() == true) {
    Serial.println("Tare complete");
  }

}

void reset() {
  EEPROM.get(calVal_eepromAdress, calFactor);
  LoadCell.setCalFactor(calFactor);
  LoadCell.tareNoDelay(); //tare
}

void calibrate() {
  Serial.println("Start calibration (tare)");

  boolean _resume = false;
  while (_resume == false) {
    LoadCell.update();
    if (Serial.available() > 0) {
      char inByte = Serial.read();
      if (inByte == 't') LoadCell.tareNoDelay();
      else if (inByte == 'r') {
        reset();
        return;
      }
    }
    if (LoadCell.getTareStatus() == true) {
      Serial.println("Tare complete");
      _resume = true;
    }
  }

  Serial.println("Calibration (200.0g)");

  float known_mass = 0;
  _resume = false;
  while (_resume == false) {
    LoadCell.update();
    if (Serial.available() > 0) {
      // Check whether an 'r' was sent before parseFloat starts
      if (Serial.peek() == 'r') {
        Serial.read(); // Remove the 'r' from the buffer
        reset();
        return;
      }
      
      known_mass = Serial.parseFloat();
      if (known_mass != 0) {
        Serial.print("Known mass is: ");
        Serial.println(known_mass);
        _resume = true;
      }
    }
  }

  LoadCell.refreshDataSet(); // refresh the dataset to be sure that the known mass is measured correct
  float newCalibrationValue = LoadCell.getNewCalibration(known_mass); // get the new calibration value

  #if defined(ESP8266)|| defined(ESP32)
    EEPROM.begin(512);
  #endif
    EEPROM.put(calVal_eepromAdress, newCalibrationValue);
  #if defined(ESP8266)|| defined(ESP32)
    EEPROM.commit();
  #endif
    EEPROM.get(calVal_eepromAdress, newCalibrationValue);

  Serial.println("End calibration");

  // Have the weights removed again
  _resume = false;
  while (_resume == false) {
    LoadCell.update();
    if (Serial.available() > 0) {
      char inByte = Serial.read();
      if (inByte == 't') LoadCell.tareNoDelay();
      else if (inByte == 'r') {
        reset();
        return;
      }
    }
    if (LoadCell.getTareStatus() == true) {
      Serial.println("Tare complete");
      _resume = true;
    }
  }
}

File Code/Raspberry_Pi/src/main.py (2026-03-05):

"""

    Pick-by-Light System
    -------------------------------------------------------------------------------
    Main programm for Raspberry Pi to control a Pick-by-Light system based on a
    infrared reflection principle. After calibration, the vehicle to be collected
    can be chosen via a rfid readout. Handles can then be detected via the MCP23017
    communication. Also, the load cell delivers the amount of added components.
    With these information, the system can automatically change to the next item.
    Above the current item box, LEDs light up to help the user.

    The database is loaded from an excel file to allow simple changements.

    The load cell can be calibrated before the picking of items has started by long
    pressing the push button. Errors can be acknowledged by pushing the push button.
    You can manually change to the nex item by pushing the button for a short time.
    When pushing the button for a longer time (> 2 seconds), it switches to the
    previous item. The communication with the GUI class is done via 'to_qui_queue'
    and 'from_gui_queue'.

    The program is using an extra thread-loop for retrieving the sensor values as
    the GUI also needs to run as a loop.

    Author: Andreas Katzenberger
    Date: 2026-02-22

"""

import multiprocessing as mp
import queue
import time
from multiprocessing.context import Process as mpProcess
from multiprocessing.queues import Queue as mpQueue
from multiprocessing.synchronize import Event as mpEvent

import board
import pigpio

from gui import start_viewer
from lego_database import read_excel_matrices
from load_cell import LoadCell
from mcp23017 import MCP23017
from rafi_press_button import RAFI_Push_Button
from rfid_reader import RFIDReader
from texts import texts
from ws2812b_led_strip import WS2812B, RGB_Color

# Language
language: str = "de"

# Usage of load cell
USE_LOAD_CELL = True

# Constants / Hardware assignments
MCP_INTERRUPT_PINS = [4, 17, 27, 22, 16, 24, 23]
LED_COUNT_LARGE_STRIP = 865  # Number of LEDs in the large strip
LED_COUNT_SHORT_STRIP = 15  # Number of LEDs in the short strip
RED = RGB_Color(255, 0, 0)
YELLOW = RGB_Color(255, 255, 0)
GREEN = RGB_Color(0, 255, 0)


def setup(
    dictionary: dict[str, str], push_button_queue: mpQueue, load_cell_usage: bool
) -> tuple[
    pigpio.pi,
    list[MCP23017],
    WS2812B,
    WS2812B,
    RAFI_Push_Button,
    RFIDReader,
    LoadCell | None,
    dict[str, dict[str, list[list[dict[str, float | str]]]]],
]:
    # Initialize pigpio
    pi: pigpio.pi = pigpio.pi()
    if not pi.connected:
        raise RuntimeError(dictionary["pigpio_not_connected"])

    # MCP instances
    mcps: list[MCP23017] = [
        MCP23017(idx, 1, int_pin, pi) for idx, int_pin in enumerate(MCP_INTERRUPT_PINS)
    ]

    large_led_strip: WS2812B = WS2812B(board.D12, LED_COUNT_LARGE_STRIP)
    short_led_strip: WS2812B = WS2812B(board.D13, LED_COUNT_SHORT_STRIP)

    push_button: RAFI_Push_Button = RAFI_Push_Button(push_button_queue, 26, pi)

    rfid_reader: RFIDReader = RFIDReader()

    load_cell: LoadCell | None = None
    if load_cell_usage is True:
        load_cell = LoadCell()

    database: dict[str, dict[str, list[list[dict[str, float | str]]]]] = read_excel_matrices(
        "data/Fahrzeuge_Stueckzahluebersicht.xlsx"
    )

    return pi, mcps, large_led_strip, short_led_strip, push_button, rfid_reader, load_cell, database


def light_up_leds_on_side(short_led_strip: WS2812B, side: str) -> None:
    if side.lower() == "left":
        short_led_strip.light_up([(idx, GREEN) for idx in range(8, 15)])
    elif side.lower() == "right":
        short_led_strip.light_up([(idx, GREEN) for idx in range(0, 8)])


def measure_loop_without_load_cell(
    to_gui_queue: mpQueue,
    from_gui_queue: mpQueue,
    mcps: list[MCP23017],
    large_led_strip: WS2812B,
    short_led_strip: WS2812B,
    push_button_queue: mpQueue,
    rfid_reader: RFIDReader,
    stop_signal: mpEvent,
) -> None:
    """
    This function should run in a thread parallel to the GUI.
    """
    push_button_press_time: float | None = None
    button_press_duration: float = 0.0
    rfid_read_complete: bool = False
    push_button_short_pressed: bool = False
    first_short_press_detected: bool = False
    second_short_press_detected: bool = False
    mcp_calibration_finished: bool = False
    rfid_wait_for_exchange: bool = False
    actual_side: str = "Left"

    try:
        while not stop_signal.is_set():
            try:
                while True:
                    msg = from_gui_queue.get_nowait()
                    event_type = msg.get("event")
                    value = msg.get("value")

                    if event_type == "New box":
                        actual_side = "Left" if value.startswith("L") else "Right"
                        row: int = int(value.split(".")[0][-1])
                        column: int = int(value.split(".")[1][0])
                        # print(f"Row: {row}")
                        # print(f"Column: {column}")
                        light_up_leds_on_side(short_led_strip, actual_side)
                        light_up_leds_from_position(large_led_strip, actual_side, row, column)
                        # print("New LEDs lighting")
                    elif event_type == "Vehicle complete":
                        push_button_press_time = None
                        rfid_read_complete = False
                        push_button_short_pressed = False
                        first_short_press_detected = False
                        second_short_press_detected = False
                        rfid_wait_for_exchange = True
                        large_led_strip.turn_off()
                    elif event_type == "Error cleared":
                        light_up_leds_on_side(short_led_strip, actual_side)
                    elif event_type == "Error occurred":
                        short_led_strip.light_up_all(RED)

            except queue.Empty:
                pass

            # Calibration (at the beginning)
            if not mcp_calibration_finished:
                all_mcp_calibrated: bool = True
                for idx, mcp in enumerate(mcps):
                    mcp.update()
                    if not mcp.is_calibration_finished():
                        all_mcp_calibrated = False
                if all_mcp_calibrated:
                    # print("MCPs calibrated")
                    # for idx, mcp in enumerate(mcps):
                    #     mcp.print_calibration_values(idx)

                    mcp_calibration_finished = True
                    to_gui_queue.put({"event": "All calibrations completed", "value": True})
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

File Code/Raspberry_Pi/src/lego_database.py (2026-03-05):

"""

    Pick-by-Light System
    -------------------------------------------------------------------
    Offers a function to convert an excel file into a dict containing
    all data for the display on the GUI. Each sheet is read separately,
    cells are checked for numerical values line by line. Numerical
    values are stored in a matrix (list of lines), cells without
    numbers are kept as `None`.

    Author: Andreas Katzenberger
    Date: 2026-02-22

"""

import os
from datetime import datetime as dt

import openpyxl


def _is_number(value: float | int | str | dt | bool | None) -> bool:
    """
    Checks whether 'value' can be interpreted as a number.
    Boolean values are excluded (since bool is a subclass of int in Python).
    """
    if value is None:
        return False
    if isinstance(value, bool):
        return False
    if isinstance(value, dt):
        return False
    try:
        # accepts ints, floats, and numeric strings
        float(value)
        return True
    except Exception:
        return False


def read_excel_matrices(path: str) -> dict[str, dict[str, list[list[dict[str, float | str]]]]]:
    """
    Loads the Excel file and returns a dict:

    key: sheet name (str)
    value: matrix as a list of rows; each cell is `float` or `None`.

    Searches rows containing at least one numeric cell.
    These are the lines containing the amount of components for a vehicle.
    From that, it collects the information from the lines above (weight, id, name).
    """
    if not os.path.exists(path):
        raise FileNotFoundError(f"Datei nicht gefunden: {path}")

    wb: openpyxl.workbook.workbook.Workbook = openpyxl.load_workbook(path, data_only=True)
    result: dict[str, dict[str, list[list[dict[str, float | str]]]]] = {}

    excel_row_idx: int = 0
    counter: int = 0
    amount_row: bool = False

    for sheet in wb.worksheets:
        matrix: dict[str, list[list[dict[str, float | str]]]] = {}
        orientation: str = "Unknown"
        for row_idx, row in enumerate(sheet.iter_rows(values_only=True)):
            # Check whether the line contains at least one number.
            excel_row_idx = row_idx + 1
            counter = 0
            amount_row = False
            for cell in row:
                if _is_number(cell):
                    counter += 1
                elif isinstance(cell, str) and cell.strip().lower() == "anzahl":
                    amount_row = True
                elif isinstance(cell, str) and cell.strip().lower() == "linke seite":
                    orientation = "Left_Side"
                elif isinstance(cell, str) and cell.strip().lower() == "rechte seite":
                    orientation = "Right_Side"
            if orientation == "Unknwon" or amount_row is False or counter <= 0 or counter % 7 != 0:
                continue

            processed_row: list[dict[str, float | str]] = []
            for col_idx, cell in enumerate(row):
                if _is_number(cell):
                    id = sheet[excel_row_idx - 2][col_idx].value
                    weight = sheet[excel_row_idx - 1][col_idx].value
                    processed_row.append(
                        {
                            "name": str(sheet[excel_row_idx - 3][col_idx - 2].value),
                            "id": str(id),
                            "weight": float(weight),
                            "amount": float(cell),
                        }
                    )
            if matrix.keys().__contains__(orientation) is False:
                matrix[orientation] = []
            matrix[orientation].append(processed_row)

        result[sheet.title] = matrix

    return result

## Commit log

2026-03-05 Add CAD files
    [Deckel_Platinegehäuse.stl, Deckel_lang.stl, Kabelkanaldeckel_18.5cm.stl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]
2026-03-05 Add code files
    [config.txt]
2026-03-05 Add circuit folder
2026-03-06 Upload excel file and GUI images
    [Fahrzeuge_Stueckzahluebersicht.xlsx]
